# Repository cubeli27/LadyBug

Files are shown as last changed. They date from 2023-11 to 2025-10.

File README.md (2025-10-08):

# LadyBug-v1.1

STM32F103RCT6TR-based Embedded Development Platform with IMU, Power Management, and PWM Control
<p align="center">
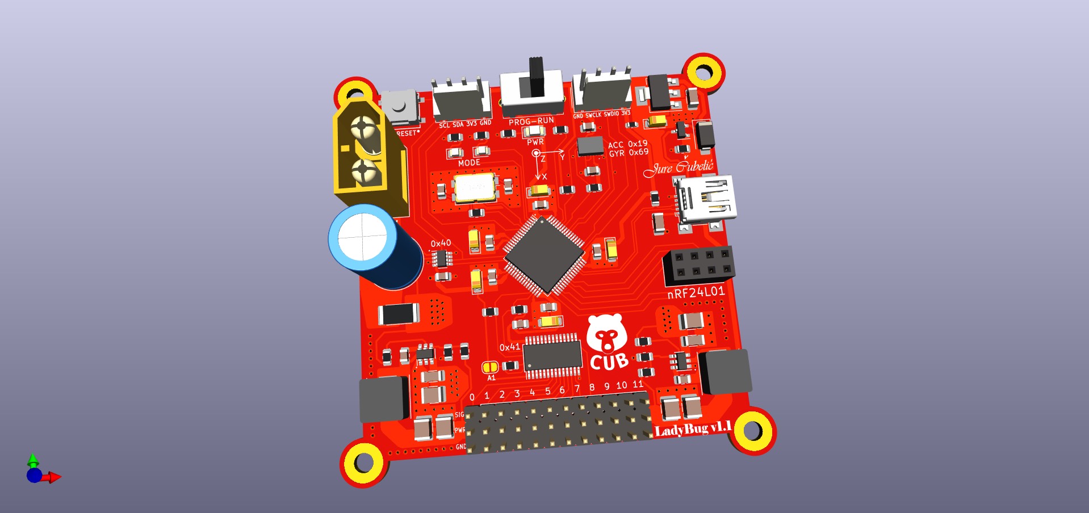
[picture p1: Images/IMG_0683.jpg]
  
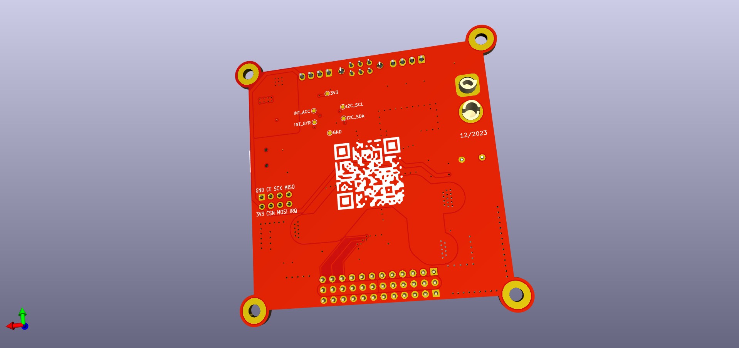
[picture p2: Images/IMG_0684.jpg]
  
</p>

## Overview

This project showcases an embedded system built around the STM32F103RCT6TR microcontroller. It incorporates advanced features like an integrated Inertial Measurement Unit (IMU), efficient power management, and precise PWM control. The system is designed for learners and enthusiasts interested in STM32 programming, embedded systems, PCB design, and robotics.

## Table of Contents

- [Features](#features)
- [Getting Started](#getting-started)
- [Final Product](#final-product)
- [Project Structure](#project-structure)
- [Sponsor Acknowledgment](#sponsor-acknowledgment)
- [License](#license)

## Features

1. **Microcontroller:** STM32F103RCT6, providing a powerful platform for development.
2. **Connectivity:** USB, SWD, I2C, and SPI connectors for versatile interfacing.
3. **Sensors:** Integrated BMI088 IMU and INA219 voltage/current/power sensor for precise data acquisition.
4. **PWM Control:** PCA9685 PWM driver for controlling up to 12 servos simultaneously.
5. **Power Options:** Supports both USB and LiPo batteries, featuring auto-select circuitry for seamless power management.
6. **Efficient Power Delivery:** Switched-Mode Power Supply (SMPS) ensures efficiency and is capable of delivering up to 10A.

## Getting Started

1. **Clone the repository.**
   ```bash
   git clone https://github.com/cubeli27/LadyBug
2. **Order your own LadyBug.**
   
   To manufacture your LadyBug, access the fabrication files in "PCB_Design/fabrication". I ordered the PCBs from PCBWay and handled the assembly myself.
4. **Firmware:**

   Start using LadyBug with the template project located in "Source_Code". 

## Final Product

Here is the complete LadyBug-v1.1 robot, featuring the assembled PCB, 3D-printed body, and fully integrated servo motors. This section showcases how the finished robot looks.

<p align="center">
  <img src="Images/finalresult.png" alt="LadyBug Fully Assembled" width="60%">
</p>

To see LadyBug in action, check out the video demonstration [here](https://youtube.com/shorts/0U5EO-w3WB0?si=tFpQQ-5Q2gVJXG-p).

## Project Structure

- **3D_Model:** Stores the 3D printed part models. (Currently not available; actual models will be added in the future)
- **Images:** Stores project-related images.
- **LadyBug1.0-files:** Relevant documentation for the first prototype. (Note: Currently irrelevant and should be disregarded.)
- **PCB_Design:** Contains PCB design-related files, including Gerber files necessary for manufacturing. 
- **Source_Code:** Houses the source code for the embedded system project.
- **LICENSE:** Licensing information for the project.
- **README.md:** The main documentation file providing an overview of the project, and features.

## Sponsor Acknowledgment

I extend my heartfelt gratitude to PCBWay for their generous support and contribution to this project. Their commitment to fostering innovation and learning in PCB Design has been instrumental in making this endeavor possible. I am very pleased with the customer support every step of the way and even more with the quality of delivered printed circuit boards.
<p align="left">
  <img src="Images/image_672069131.JPG" alt="Image 1" width="60%">
  <img src="https://github.com/cubeli27/LadyBug/assets/134604815/8978de7c-6bcc-40be-b4ff-5b680a61df90" alt="Sponsor Logo" width="20%">
</p>

### Contact Information

For inquiries or to learn more about PCBWay, please visit [their website](https://www.pcbway.com/) or contact them at service@pcbway.com.

## License
This project is licensed under the MIT License.

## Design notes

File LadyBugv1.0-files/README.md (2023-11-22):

# LadyBug-v1.0
This is still a work in progress.

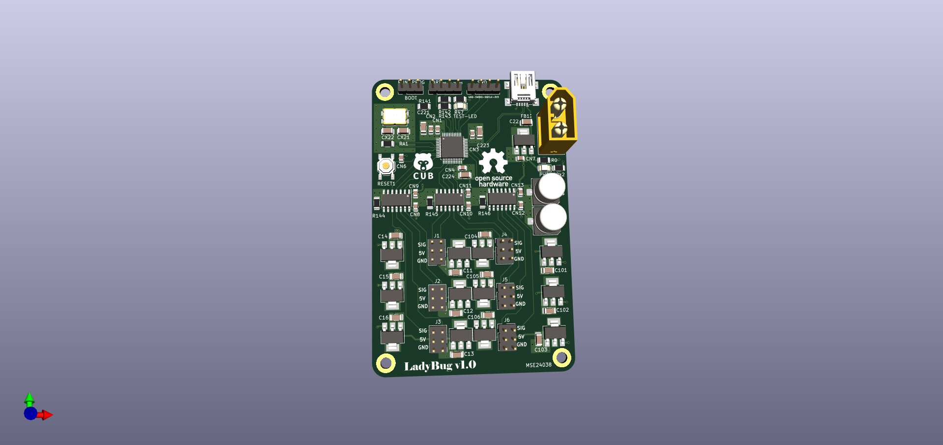
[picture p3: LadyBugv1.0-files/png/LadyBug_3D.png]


Mistakes were made, lessons were learned, and assembly was a nightmare but luckily my special skills of soldering flying wires came through and saved the day.
The board is fully functional and works as it should but obviously ugly. 



I'll use it to learn stm32 as I never programmed one before designing this board and it's been fun so far. Wish me luck.

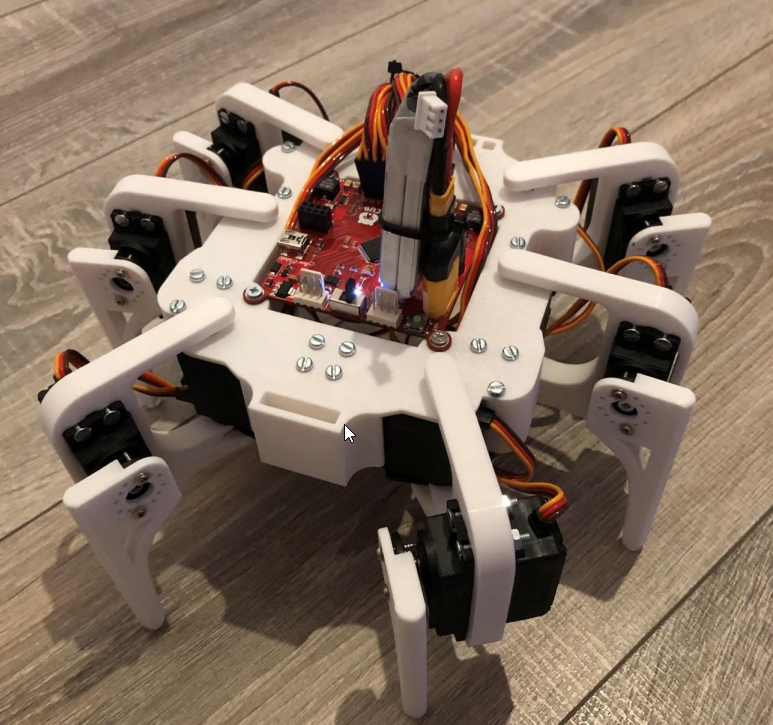
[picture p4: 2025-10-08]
Images/finalresult.png

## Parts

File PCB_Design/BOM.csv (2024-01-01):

# | Reference | Qty | Value | Footprint | DNP
1 | A1, R1, R13, R14, R16, R17 | 6 | 10k | Resistor_SMD:R_0805_2012Metric
2 | C1, C4, C5, C6, C7, C8, C20, C25, C28, C29, C30, C31 | 12 | 100n | Capacitor_SMD:C_0805_2012Metric
3 | C2, C3 | 2 | 22p | Capacitor_SMD:C_0805_2012Metric
4 | C9, C10, C11, C12, C14, C19 | 6 | 22u | Capacitor_Tantalum_SMD:CP_EIA-3216-18_Kemet-A
5 | C13, C16, C18, C24 | 4 | 10u | Capacitor_SMD:C_1206_3216Metric
6 | C15 | 1 | 1000u | Capacitor_THT:C_Radial_D10.0mm_H20.0mm_P5.00mm
7 | C17, C21, C22, C23, C26, C27 | 6 | 47u | Capacitor_SMD:C_1210_3225Metric
8 | D1 | 1 | BLUE | LED_SMD:LED_0805_2012Metric
9 | D2 | 1 | RED | LED_SMD:LED_0805_2012Metric
10 | D3 | 1 | WHITE | LED_SMD:LED_1206_3216Metric
11 | D4 | 1 | D_Schottky | Diode_SMD:D_SMA
12 | FB1 | 1 | FerriteBead | Fuse:Fuse_0603_1608Metric
13 | IC1 | 1 | BMI088 | BMI088
14 | J1 | 1 | nRF24L01 | Connector_PinSocket_2.54mm:PinSocket_2x04_P2.54mm_Vertical
15 | J2, J3 | 2 | Conn_01x04 | Connector_Molex:Molex_KK-254_AE-6410-04A_1x04_P2.54mm_Vertical
16 | J4 | 1 | USB_B_Mini | Connector_USB:USB_Mini-B_Wuerth_65100516121_Horizontal
17 | J5 | 1 | XT60 | Connector_AMASS:AMASS_XT60-M_1x02_P7.20mm_Vertical
18 | L1, L2 | 2 | 3u3 | 3.3uH:WE-HCI_7030_7040_705023
19 | PWR1 | 1 | Conn_02x12_Odd_Even | Connector_PinHeader_2.54mm:PinHeader_2x12_P2.54mm_Vertical
20 | Q1 | 1 | FDN340P | Package_TO_SOT_SMD:SOT-23
21 | R2 | 1 | 470 | Resistor_SMD:R_0805_2012Metric
22 | R3, R4, R5, R10 | 4 | 1k5 | Resistor_SMD:R_0805_2012Metric
23 | R6, R7, R8, R9 | 4 | 4k7 | Resistor_SMD:R_0805_2012Metric
24 | R11 | 1 | R0.0100 | Resistor_SMD:R_2512_6332Metric
25 | R12 | 1 | 100k | Resistor_SMD:R_0805_2012Metric
26 | R15, R18 | 2 | 56k | Resistor_SMD:R_0805_2012Metric
27 | SIG1 | 1 | Conn_01x12 | Connector_PinHeader_2.54mm:PinHeader_1x12_P2.54mm_Vertical
28 | SW1 | 1 | SW_DPST | PushButton:SW_B3SL-1002P_OMR
29 | SW2 | 1 | SW_Push_DPDT | 1_My_custom_footprint_library:SlideSW
30 | U2 | 1 | STM32F103RCT6TR | Package_QFP:LQFP-64_10x10mm_P0.5mm
31 | U3 | 1 | AZ1117-3.3 | Package_TO_SOT_SMD:SOT-223-3_TabPin2
32 | U4, U5 | 2 | TPS565208 | Package_TO_SOT_SMD:SOT-23-6
33 | U6 | 1 | INA219AIDCNR | Package_TO_SOT_SMD:SOT-23-8
34 | U7 | 1 | PCA9685PW | Package_SO:TSSOP-28_4.4x9.7mm_P0.65mm
35 | Y1 | 1 | Crystal_GND24 | Crystal:Crystal_SMD_EuroQuartz_MQ-4Pin_7.0x5.0mm

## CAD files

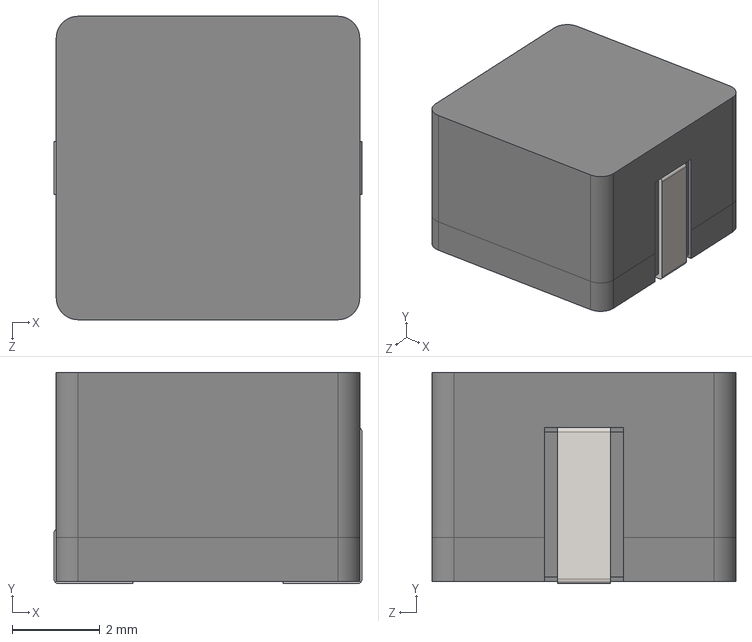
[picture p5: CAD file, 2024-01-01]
PCB_Design/3Dmodels/3.3uH.stp
7.00 x 4.80 x 6.90 mm

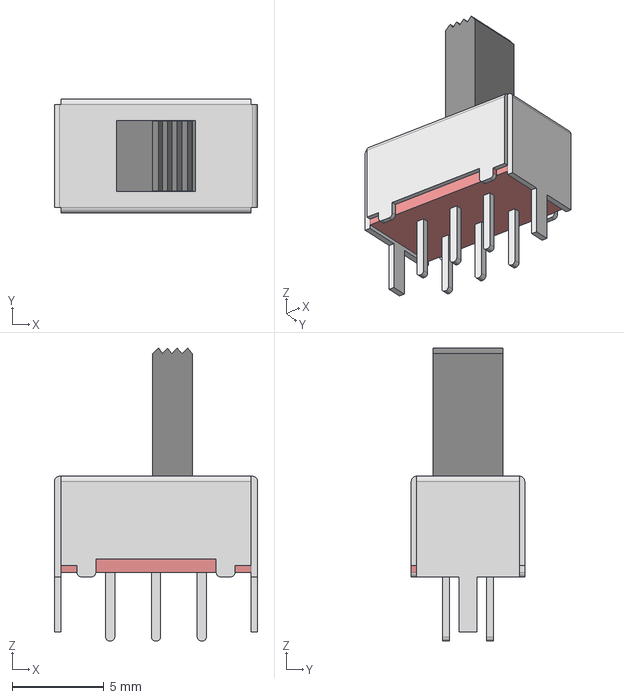
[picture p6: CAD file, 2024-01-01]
PCB_Design/3Dmodels/SlideSW.stp
11.1 x 6.20 x 16.0 mm

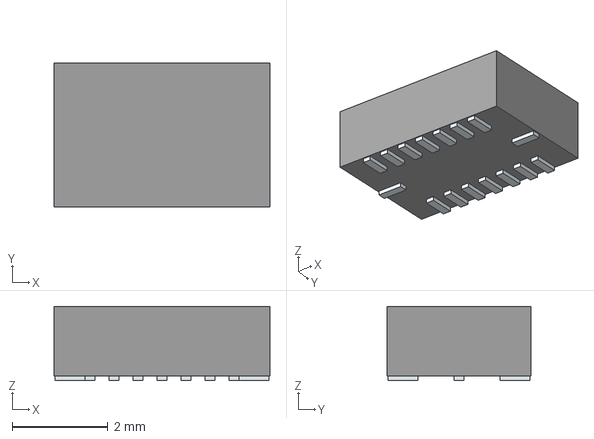
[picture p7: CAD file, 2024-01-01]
PCB_Design/3Dmodels/BMI088.stp
4.50 x 3.00 x 1.55 mm
Pins

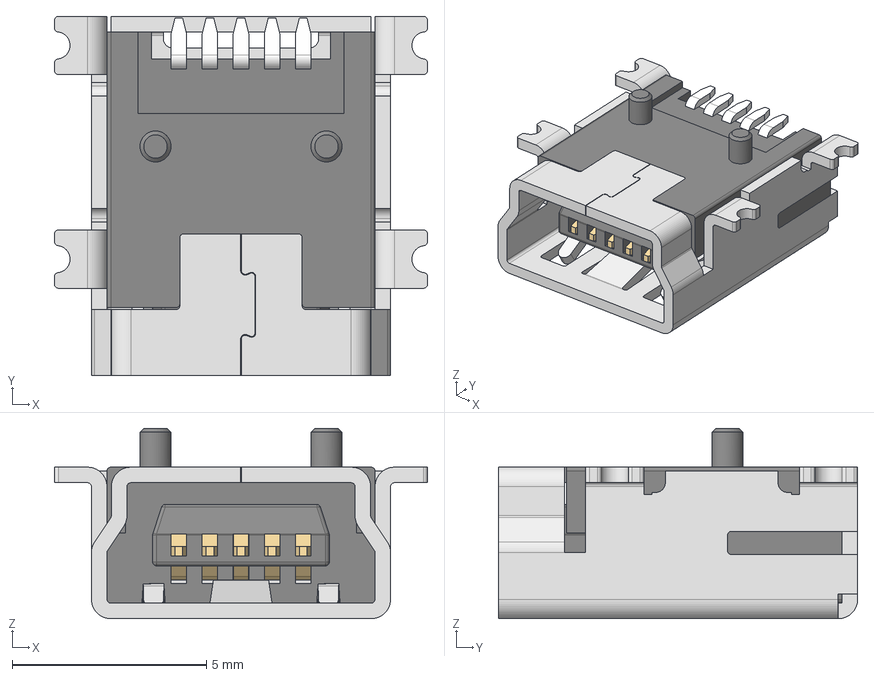
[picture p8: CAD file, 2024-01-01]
PCB_Design/3Dmodels/USB-Bmini.stp
9.60 x 9.25 x 4.90 mm
Shielding
Insulator
Pin_1 x 5

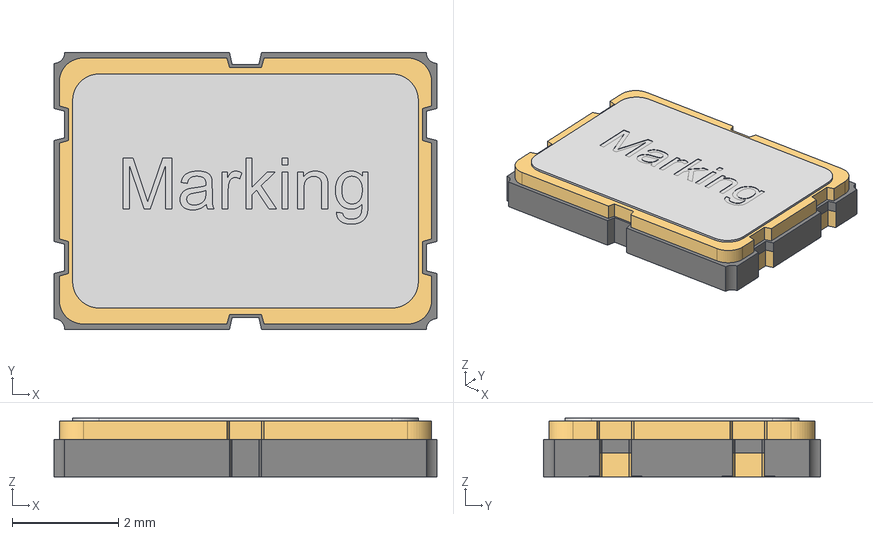
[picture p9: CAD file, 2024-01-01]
PCB_Design/3Dmodels/Crystal16Mhz.stp
7.20 x 5.20 x 1.10 mm
Pins
Cover

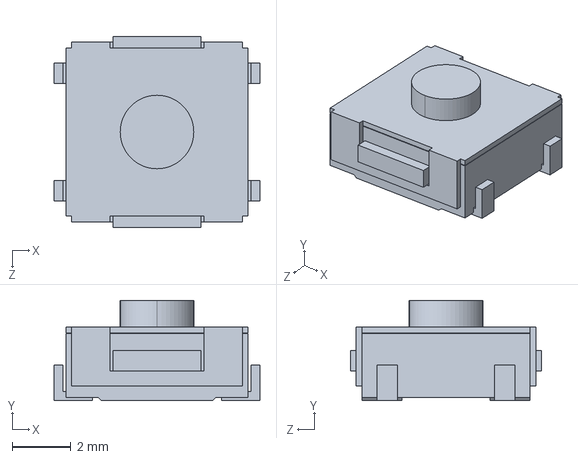
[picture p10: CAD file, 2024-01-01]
PCB_Design/3Dmodels/PushButton.STEP
7.00 x 3.40 x 6.50 mm

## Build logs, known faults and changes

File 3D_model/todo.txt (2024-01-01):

3D Models Placeholder

The 3D models for this project are currently under development and will be added here soon.
If you're looking for updates or have specific inquiries, please check the project documentation or contact the project maintainers.

Thank you for your understanding.

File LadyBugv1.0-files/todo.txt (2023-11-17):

This was a bold project idea to first design something with STM32 and figure out programming and the Cube IDE later which worked out much smoother than everything else.
This will definitely be a redesign and this repo will serve as a reference for me on what mistakes not to make and what painful lessons I learned from it.

1. LQFP-48 package: let the fab house assemble it or get something bigger if you're soldering it yourself especially if the solder paste is old.
2. "The output-enable (OE) input circuit is designed so that
it is supplied by VCCA and when the (OE) input is low, all outputs are placed in the high-impedance state." and "The TXB0104 device is designed so the OE input
circuit is supplied by VCCA."  Which led me to believ it is internally connected which is wrong and should be designed as such.
3. SWCLK pin 14, and SWDIO is pin 13 NOT 15
4. A kill switch for the servos would be convenient.
5. A switch for the Boot would be convenient.
6. UART -> I2C , silkscreen wrong.
7. FB wrong footprint
8. 5v LDO  output cap should be bigger and input cap?
9. Stiching Vias missing, maybe a good idea to add.
10.

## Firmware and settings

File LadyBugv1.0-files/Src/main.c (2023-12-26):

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
/* Includes ------------------------------------------------------------------*/
#include "main.h"

/* USER CODE BEGIN Includes */
#include "string.h"

/* USER CODE END Includes */

I2C_HandleTypeDef hi2c1;

TIM_HandleTypeDef htim1;
TIM_HandleTypeDef htim2;
TIM_HandleTypeDef htim3;
TIM_HandleTypeDef htim15;

PCD_HandleTypeDef hpcd_USB_FS;

void SystemClock_Config(void);
static void MX_GPIO_Init(void);
static void MX_TIM1_Init(void);
static void MX_TIM2_Init(void);
static void MX_TIM3_Init(void);
static void MX_TIM15_Init(void);
static void MX_I2C1_Init(void);
static void MX_USB_PCD_Init(void);
/* USER CODE BEGIN PFP */
void BugDead(void); // Legs just on the ground
void BugStandUp(void); // Bug Stands Upright
void BugStandLow(void); // Bug stands Low
void BugLegsUp(void); // Bug lifts Legs Up

/* USER CODE END PFP */

/* USER CODE BEGIN 0 */
void BugDead(void)
{
	//Feet on the Floor
	htim2.Instance->CCR1 = 70; // Left Back Foot Directly On Ground
	htim2.Instance->CCR3 = 79; // Left Front Foot Directly On Ground
	htim15.Instance->CCR2 = 75; // Right Front Foot Directly On Ground
	htim1.Instance->CCR2 = 75; // Right Left Foot Directly On Ground
	//Shoulder angle TODO
}
void BugStandUp(void)
{
	//Legs push the body up
	htim2.Instance->CCR1 = 50; // LB foot
	htim2.Instance->CCR3 = 99; // LF foot
	htim15.Instance->CCR2 = 55; // RF foot
	htim1.Instance->CCR2 = 95; // RB foot
	//Shoulder Angle TODO
}
void BugStandLow(void)
{
	//Feet on the Floor
	htim2.Instance->CCR1 = 67; // Left Back Foot Directly On Ground
	htim2.Instance->CCR3 = 82; // Left Front Foot Directly On Ground
	htim15.Instance->CCR2 = 72; // Right Front Foot Directly On Ground
	htim1.Instance->CCR2 = 78; // Right Left Foot Directly On Ground
	//Shoulder angle TODO
}
void BugLegsUp(void)
{
	// Legs of the floor and point up
	htim2.Instance->CCR1 = 80; //
	htim2.Instance->CCR3 = 69; //
	htim15.Instance->CCR2 = 85; //
	htim1.Instance->CCR2 = 65; //
	//Shoulder Angle TODO
}
/* USER CODE END 0 */

/**
  * @brief  The application entry point.
  * @retval int
  */
int main(void)
{
  /* MCU Configuration--------------------------------------------------------*/

  /* Reset of all peripherals, Initializes the Flash interface and the Systick. */
  HAL_Init();

  /* Configure the system clock */
  SystemClock_Config();

  /* Initialize all configured peripherals */
  MX_GPIO_Init();
  MX_TIM1_Init();
  MX_TIM2_Init();
  MX_TIM3_Init();
  MX_TIM15_Init();
  MX_I2C1_Init();
  MX_USB_PCD_Init();
  /* USER CODE BEGIN 2 */
  //tim1
  HAL_TIM_PWM_Start(&htim1, TIM_CHANNEL_1);	//start		BRS
  HAL_TIM_PWM_Start(&htim1, TIM_CHANNEL_2);	//start		BRF
  //tim15
  HAL_TIM_PWM_Start(&htim15, TIM_CHANNEL_1);//start		MRS
  HAL_TIM_PWM_Start(&htim15, TIM_CHANNEL_2);//start		MRF
  //tim2
  HAL_TIM_PWM_Start(&htim2, TIM_CHANNEL_1);//start		BLF
  HAL_TIM_PWM_Start(&htim2, TIM_CHANNEL_2);//start		BLS
  HAL_TIM_PWM_Start(&htim2, TIM_CHANNEL_3);//start		MLF
  HAL_TIM_PWM_Start(&htim2, TIM_CHANNEL_4);//start		MLS
  //tim3
  HAL_TIM_PWM_Start(&htim3, TIM_CHANNEL_1);//start		TLF
  HAL_TIM_PWM_Start(&htim3, TIM_CHANNEL_2);//start		TLS
  HAL_TIM_PWM_Start(&htim3, TIM_CHANNEL_3);//start		TRS
  HAL_TIM_PWM_Start(&htim3, TIM_CHANNEL_4);//start		TRF
  /* USER CODE END 2 */

  /* Infinite loop */
  /* USER CODE BEGIN WHILE */
  while (1)
  {
    /* USER CODE END WHILE */

    /* USER CODE BEGIN 3 */
	BugStandUp();
	HAL_Delay(500);
	BugStandLow();
	HAL_Delay(500);
	BugLegsUp();
	HAL_Delay(500);
	BugStandLow();
	HAL_Delay(500);


  }
  /* USER CODE END 3 */
}

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


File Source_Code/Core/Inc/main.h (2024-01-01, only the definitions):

#define LED_BLUE_Pin GPIO_PIN_13
#define LED_BLUE_GPIO_Port GPIOC
#define LED_RED_Pin GPIO_PIN_14
#define LED_RED_GPIO_Port GPIOC
#define IRQ_Pin GPIO_PIN_7
#define IRQ_GPIO_Port GPIOC
#define CE_Pin GPIO_PIN_8
#define CE_GPIO_Port GPIOC
#define CSN_Pin GPIO_PIN_9
#define CSN_GPIO_Port GPIOC
#define INT_GYR_Pin GPIO_PIN_3
#define INT_GYR_GPIO_Port GPIOB
#define INT_ACC_Pin GPIO_PIN_4
#define INT_ACC_GPIO_Port GPIOB

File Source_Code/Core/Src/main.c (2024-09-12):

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
/* Includes ------------------------------------------------------------------*/
#include "main.h"
#include "usb_device.h"

/* USER CODE BEGIN Includes */
#include "pca9685.h"
#include "BMI088.h"
#include "usbd_cdc_if.h"
#include "LadyMoves.h"
/* USER CODE END Includes */

I2C_HandleTypeDef hi2c1;
I2C_HandleTypeDef hi2c2;

SPI_HandleTypeDef hspi2;

/* USER CODE BEGIN PV */
PCA9685 pwm;
BMI088IMU imu;
/* USER CODE END PV */

void SystemClock_Config(void);
static void MX_GPIO_Init(void);
static void MX_I2C1_Init(void);
static void MX_I2C2_Init(void);
static void MX_SPI2_Init(void);
/* USER CODE BEGIN 0 */
void where_we_stand(){
	BMI088_ReadAcc(&imu);
	BMI088_ReadGyr(&imu);
	printf("Accelerom: X=%.2f m/s^2, Y=%.2f m/s^2, Z=%.2f m/s^2\n", imu.acc[1], imu.acc[0], imu.acc[2]);

	printf("Gyroscope: X=%.2f rad/s, Y=%.2f rad/s, Z=%.2f rad/s\n", imu.gyr[1], imu.gyr[0], imu.gyr[2]);

}
/* USER CODE END 0 */

/**
  * @brief  The application entry point.
  * @retval int
  */
int main(void)
{
  /* USER CODE BEGIN 1 */
	int flag=1;
  /* USER CODE END 1 */

  /* MCU Configuration--------------------------------------------------------*/

  /* Reset of all peripherals, Initializes the Flash interface and the Systick. */
  HAL_Init();

  /* Configure the system clock */
  SystemClock_Config();

  /* Initialize all configured peripherals */
  MX_GPIO_Init();
  MX_I2C1_Init();
  MX_I2C2_Init();
  MX_SPI2_Init();
  MX_USB_DEVICE_Init();
  /* USER CODE BEGIN 2 */
  PCA9685_Init(&pwm, &hi2c2);
  HAL_Delay(1000);
  /*PCA9685_SetMicros(&pwm, 0, 1500); //neutral
  PCA9685_SetMicros(&pwm, 1, 1500);	//neutral
  PCA9685_SetMicros(&pwm, 2, 1500); //neutral
  PCA9685_SetMicros(&pwm, 3, 1500); //neutral
  PCA9685_SetMicros(&pwm, 4, 1500); //neutral
  PCA9685_SetMicros(&pwm, 5, 1500); //neutral
  PCA9685_SetMicros(&pwm, 6, 1500); //neutral
  PCA9685_SetMicros(&pwm, 7, 1500); //neutral
  PCA9685_SetMicros(&pwm, 8, 1500); //neutral
  PCA9685_SetMicros(&pwm, 9, 1500); //neutral
  PCA9685_SetMicros(&pwm, 10, 1500); //neutral
  PCA9685_SetMicros(&pwm, 11, 1500); //neutral
  HAL_Delay(500);*/
  HAL_GPIO_WritePin(GPIOC,GPIO_PIN_13,GPIO_PIN_SET);

  //BMI088_Init(&imu, &hi2c1, GPIOB, GPIO_PIN_4, GPIOB, GPIO_PIN_3);
  //HAL_Delay(1000);

  /* USER CODE END 2 */

  /* Infinite loop */
  /* USER CODE BEGIN WHILE */
  while (1)
  {
    /* USER CODE END WHILE */

    /* USER CODE BEGIN 3 */
		HAL_GPIO_WritePin(GPIOC,GPIO_PIN_13,GPIO_PIN_RESET);
		HAL_Delay(500);
		HAL_GPIO_WritePin(GPIOC,GPIO_PIN_13,GPIO_PIN_SET);
		HAL_Delay(300);
		//neutral();
		//HAL_Delay(200);
		//go_sleep();
		HAL_Delay(1000);
		if(flag){
			wakeup();
			walkfast_tripod();
			turn_left();
			circle_left();
			go_sleep();
			flag=0;
		}
		HAL_Delay(1);
  }
  /* USER CODE END 3 */
}

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
/* USER CODE BEGIN 4 */
//Switch printf() to Serial Monitor COM Port
int _write(int file, char *ptr, int len) {
    CDC_Transmit_FS((uint8_t*) ptr, len); return len;
}
/* USER CODE END 4 */
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


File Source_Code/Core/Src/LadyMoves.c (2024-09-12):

/*
 * LadyMoves.c
 *
 *  Created on: Feb 23, 2024
 *      Author: Jurin PC
 */
#include "LadyMoves.h"
extern PCA9685 pwm;  //use this to avoid passing PCA9685 *pca

void walkfast_tripod(){
	//start neutral LEFT GAIT
	PCA9685_SetMicros(&pwm,0,1500);//BL leg
	PCA9685_SetMicros(&pwm,1,1500);//BL shoulder
	PCA9685_SetMicros(&pwm,4,1500);//FL leg
	PCA9685_SetMicros(&pwm,5,1500);//FL shoulder
	PCA9685_SetMicros(&pwm,8,1500);//MR leg
	PCA9685_SetMicros(&pwm,9,1500);//MR shoulder
	//start neutral RIGHT GAIT
	PCA9685_SetMicros(&pwm,6,1500);//BR leg
	PCA9685_SetMicros(&pwm,7,1500);//BR shoulder
	PCA9685_SetMicros(&pwm,10,1500);//FR leg
	PCA9685_SetMicros(&pwm,11,1500);//FR shoulder
	PCA9685_SetMicros(&pwm,2,1500);//ML leg
	PCA9685_SetMicros(&pwm,3,1500);//ML shoulder
	HAL_Delay(200);
	for(int i=0 ; i<5 ; i++){
//-----------------------------------------------------------------------------------------------------------------//
//RIGHT GAIT LIFT---
		PCA9685_SetMicros(&pwm,6,1300);//BR leg
		PCA9685_SetMicros(&pwm,10,1300);//FR leg
		PCA9685_SetMicros(&pwm,2,1700);//ML leg
		HAL_Delay(50);
//RIGHT GAIT SWEEP%%%
		PCA9685_SetMicros(&pwm,7,1500);//BR shoulder
		PCA9685_SetMicros(&pwm,11,1500);//FR shoulder
		PCA9685_SetMicros(&pwm,3,1500);//ML shoulder
//LEFT GAIT PUSH***
		PCA9685_SetMicros(&pwm,1,1000);//BL shoulder
		PCA9685_SetMicros(&pwm,5,1000);//FL shoulder
		PCA9685_SetMicros(&pwm,9,1650);//MR shoulder
		HAL_Delay(200);
// RIGHT GAIT DOWN!!
		PCA9685_SetMicros(&pwm,6,1500);//BR leg
		PCA9685_SetMicros(&pwm,10,1500);//FR leg
		PCA9685_SetMicros(&pwm,2,1500);//ML leg
		HAL_Delay(100);
//LEFT GAIT LIFT---
		PCA9685_SetMicros(&pwm,0,1700);//BL leg
		PCA9685_SetMicros(&pwm,4,1700);//FL leg
		PCA9685_SetMicros(&pwm,8,1300);//MR leg
		HAL_Delay(50);
//LEFT GAIT SWEEP%%%
		PCA9685_SetMicros(&pwm,1,1500);//BL shoulder
		PCA9685_SetMicros(&pwm,5,1500);//FL shoulder
		PCA9685_SetMicros(&pwm,9,1500);//MR shoulder
//RIGHT GAIT PUSH***
		PCA9685_SetMicros(&pwm,7,2000);//BR shoulder
		PCA9685_SetMicros(&pwm,11,2000);//FR shoulder
		PCA9685_SetMicros(&pwm,3,1350);//ML shoulder
		HAL_Delay(200);
//LEFT GAIT DOWN!!
		PCA9685_SetMicros(&pwm,0,1500);//BL leg
		PCA9685_SetMicros(&pwm,4,1500);//FL leg
		PCA9685_SetMicros(&pwm,8,1500);//MR leg
		HAL_Delay(100);
	  }
	PCA9685_SetMicros(&pwm, 0, 1500); //neutral BL leg
	PCA9685_SetMicros(&pwm, 1, 1500); //neutral BL shoulder
	PCA9685_SetMicros(&pwm, 2, 1500); //neutral ML leg
	PCA9685_SetMicros(&pwm, 3, 1500); //neutral ML shoulder
	PCA9685_SetMicros(&pwm, 4, 1500); //neutral FL leg
	PCA9685_SetMicros(&pwm, 5, 1500); //neutral FL shoulder

	PCA9685_SetMicros(&pwm, 6, 1500); //neutral BR leg
	PCA9685_SetMicros(&pwm, 7, 1500); //neutral BR shoulder
	PCA9685_SetMicros(&pwm, 8, 1500); //neutral MR leg
	PCA9685_SetMicros(&pwm, 9, 1500); //neutral MR shoulder
	PCA9685_SetMicros(&pwm, 10, 1500);//neutral FR leg
	PCA9685_SetMicros(&pwm, 11, 1500);//neutral FR shoulder
//end
}
void walkslow_tripod(){
	//start neutral LEFT GAIT
	PCA9685_SetMicros(&pwm,0,1500);//BL leg
	PCA9685_SetMicros(&pwm,1,1500);//BL shoulder
	PCA9685_SetMicros(&pwm,4,1500);//FL leg
	PCA9685_SetMicros(&pwm,5,1500);//FL shoulder
	PCA9685_SetMicros(&pwm,8,1500);//MR leg
	PCA9685_SetMicros(&pwm,9,1500);//MR shoulder 1400
	//start neutral RIGHT GAIT
	PCA9685_SetMicros(&pwm,6,1500);//BR leg
	PCA9685_SetMicros(&pwm,7,1500);//BR shoulder
	PCA9685_SetMicros(&pwm,10,1500);//FR leg
	PCA9685_SetMicros(&pwm,11,1500);//FR shoulder
	PCA9685_SetMicros(&pwm,2,1500);//ML leg
	PCA9685_SetMicros(&pwm,3,1500);//ML shoulder 1600
	HAL_Delay(200);
	for(int i=0 ; i<5 ; i++){
//-----------------------------------------------------------------------------------------------------------------//
//RIGHT GAIT LIFT---
		PCA9685_SetMicros(&pwm,6,1300);//BR leg
		PCA9685_SetMicros(&pwm,10,1300);//FR leg
		PCA9685_SetMicros(&pwm,2,1700);//ML leg
		HAL_Delay(300);
//RIGHT GAIT SWEEP%%%
		PCA9685_SetMicros(&pwm,7,1500);//BR shoulder
		PCA9685_SetMicros(&pwm,11,1500);//FR shoulder
		PCA9685_SetMicros(&pwm,3,1500);//ML shoulder
//LEFT GAIT PUSH***
		PCA9685_SetMicros(&pwm,1,1000);//BL shoulder
		PCA9685_SetMicros(&pwm,5,1000);//FL shoulder
		PCA9685_SetMicros(&pwm,9,1650);//MR shoulder
		HAL_Delay(800);
// RIGHT GAIT DOWN!!
		PCA9685_SetMicros(&pwm,6,1500);//BR leg
		PCA9685_SetMicros(&pwm,10,1500);//FR leg
		PCA9685_SetMicros(&pwm,2,1500);//ML leg
		HAL_Delay(500);
//LEFT GAIT LIFT---
		PCA9685_SetMicros(&pwm,0,1700);//BL leg
		PCA9685_SetMicros(&pwm,4,1700);//FL leg
		PCA9685_SetMicros(&pwm,8,1300);//MR leg
		HAL_Delay(300);
//LEFT GAIT SWEEP%%%
		PCA9685_SetMicros(&pwm,1,1500);//BL shoulder
		PCA9685_SetMicros(&pwm,5,1500);//FL shoulder
		PCA9685_SetMicros(&pwm,9,1500);//MR shoulder
//RIGHT GAIT PUSH***
		PCA9685_SetMicros(&pwm,7,2000);//BR shoulder
		PCA9685_SetMicros(&pwm,11,2000);//FR shoulder
		PCA9685_SetMicros(&pwm,3,1350);//ML shoulder
		HAL_Delay(800);
//LEFT GAIT DOWN!!
		PCA9685_SetMicros(&pwm,0,1500);//BL leg
		PCA9685_SetMicros(&pwm,4,1500);//FL leg
		PCA9685_SetMicros(&pwm,8,1500);//MR leg
		HAL_Delay(500);
	  }
	PCA9685_SetMicros(&pwm, 0, 1500); //neutral BL leg
	PCA9685_SetMicros(&pwm, 1, 1500); //neutral BL shoulder
	PCA9685_SetMicros(&pwm, 2, 1500); //neutral ML leg
	PCA9685_SetMicros(&pwm, 3, 1500); //neutral ML shoulder
	PCA9685_SetMicros(&pwm, 4, 1500); //neutral FL leg
	PCA9685_SetMicros(&pwm, 5, 1500); //neutral FL shoulder

	PCA9685_SetMicros(&pwm, 6, 1500); //neutral BR leg
	PCA9685_SetMicros(&pwm, 7, 1500); //neutral BR shoulder
	PCA9685_SetMicros(&pwm, 8, 1500); //neutral MR leg
	PCA9685_SetMicros(&pwm, 9, 1500); //neutral MR shoulder
	PCA9685_SetMicros(&pwm, 10, 1500);//neutral FR leg
	PCA9685_SetMicros(&pwm, 11, 1500);//neutral FR shouder
//end
}
void neutral(){
	PCA9685_SetMicros(&pwm, 0, 1500); //neutral BL leg
	PCA9685_SetMicros(&pwm, 1, 1500); //neutral BL shoulder
	PCA9685_SetMicros(&pwm, 2, 1500); //neutral ML leg
	PCA9685_SetMicros(&pwm, 3, 1500); //neutral ML shoulder
	PCA9685_SetMicros(&pwm, 4, 1500); //neutral FL leg
	PCA9685_SetMicros(&pwm, 5, 1500); //neutral FL shoulder

	PCA9685_SetMicros(&pwm, 6, 1500); //neutral BR leg
	PCA9685_SetMicros(&pwm, 7, 1500); //neutral BR shoulder
	PCA9685_SetMicros(&pwm, 8, 1500); //neutral MR leg
	PCA9685_SetMicros(&pwm, 9, 1500); //neutral MR shoulder
	PCA9685_SetMicros(&pwm, 10, 1500);//neutral FR leg
	PCA9685_SetMicros(&pwm, 11, 1500);//neutral FR shouder
}
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

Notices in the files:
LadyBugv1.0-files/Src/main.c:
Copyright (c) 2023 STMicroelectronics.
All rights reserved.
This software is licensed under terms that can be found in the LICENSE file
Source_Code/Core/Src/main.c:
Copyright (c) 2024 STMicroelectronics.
